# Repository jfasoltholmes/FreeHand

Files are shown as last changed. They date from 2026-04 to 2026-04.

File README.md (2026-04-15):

# FreeHand 🤖✋

<p align="center">
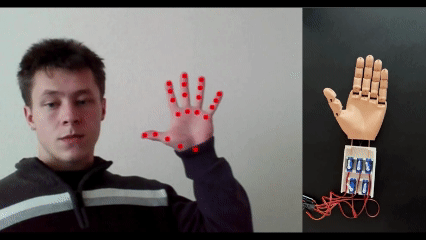
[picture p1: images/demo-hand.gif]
  
</p>

<p align="center">
  Real-time hand tracking → physical robotic hand using computer vision + embedded systems
</p>

<p align="center">
  
  
  
  
  
</p>

## ⚡ Quick Start (Vision Only)

Run the hand tracking system locally (no hardware required):

```bash
git clone https://github.com/jfasoltholmes/FreeHand
cd FreeHand
mise install
uv sync
uv run python main.py
```

⚠️ This runs the computer vision pipeline only (hand tracking + landmark visualization).

See [Hardware Setup](#hardware--assembly-notes) for full system integration.

## Why FreeHand?

FreeHand demonstrates real-time human-to-robot motion mapping using accessible tools.
The goal is to bridge computer vision and physical interaction in a simple and reproducible system.

## 🧠 FreeHand Overview
FreeHand is a real-time hand tracking system using OpenCV and MediaPipe that maps human hand motion to a motorized, 3D-printed robotic hand.

This system combines:
- 👁️ Computer vision (MediaPipe hand tracking)
- 🎯 Signal mapping (finger distance normalization)
- ⚙️ Embedded control (Bluno Beetle v1.1 microcontroller)
- 🦾 Mechanical design (3D-printed articulated hand)

## 🏗️ System Architecture

### Software
 - Real-time hand tracking using MediaPipe
 - Landmark-based finger state extraction
 - Normalized distance mapping to control signals
### Hardware
 - Bluno Beetle v1.1 microcontroller
 - 5x SG90 Servo motors (one per finger)
 - External power distribution via screw terminal
 - 6V DC power supply (recommended high current, e.g. 10A)
### Mechanical
 - 3D-printed hand structure
 - 3D-printed servo wrist mounting bracket
 - Tendon-driver finger actuation using fishing line
 - Flexible joints and segmented finger design

## 📊 Project Status
### Implemented 
 - Real-time hand tracking via webcam
 - MediaPipe landmark detection
 - Finger state extraction using normalized distance
 - Per-finger calibration mapping (open/closed → servo angle)
 - Serial communication (Python → Bluno Beetle)
 - Real-time servo actuation (full hand control)
 - Thumb-specific control model (middle MCP reference)
 - Servo-safe motion range calibration

### Current Capabilities
 - Full real-time mapping from human hand → robotic hand
 - Per-finger independent control
 - Stable demo-ready motion with calibration tuning

## 🛠 Setup (Software + Hardware)
### Software Prerequisites
- Install [mise-en-place](https://mise.jdx.dev/) (manages project Python version)
- Install [uv](https://github.com/astral-sh/uv) (fast venv + dependency sync)
- A working webcam

### Software Setup
#### Clone the repo and enter it: 
```bash
git clone https://github.com/jfasoltholmes/FreeHand
cd FreeHand
```
#### Install/use the project’s Python version:
```bash
mise install
mise use -g python@$(cat .python-version)  # optional if you want it global
```
*(If you already have mise configured, mise install is usually enough.)*

#### Create the virtual environment + install deps from lockfile:
```bash
uv sync
```
#### Run:
```bash
uv run python main.py
```
#### Notes:
 - Ensure hand_landmarker.task remains in the project root (or update the path in main.py).
 - Press q to quit.

### Firmware Prerequisites
Required to modify or flash the microcontroller:

- Install [VSCode](https://code.visualstudio.com/)
- Install [PlatformIO Extension](https://platformio.org/)

### Hardware & Assembly Notes
#### Microcontroller Setup
- The Bluno Beetle v1.1 does not come with header pins pre-installed.
- Solder header pins to all required I/O and power pins before use.
- Firmware is built and flashed using PlatformIO in VSCode.
- The board connects to your computer via USB (must support data transfer, not power-only).
#### 3D Printed Components
- Hand model files and assembly instructions [here.](https://www.thingiverse.com/thing:242639)
- Servo mounting bracket [here.](https://www.thingiverse.com/thing:3940835/files)
#### Servo Preparation & Installation
1. Use 5x SG90 servo motors (one per finger).
2. Before installation, power each servo and rotate it to 0 degrees. 
3. Attach the servo lever arm with the point facing toward the hand.
4. Install servos into the wrist mount:
    - The mount includes screw holes, but super glue can be used for tighter placement.
    - Ensure spacing prevents servo arms from colliding.
#### Tendon Routing
- Use stiff fishing line as tendons.
1. Thread each line through the servo holder holes.
2. Continue routing through the base of the hand.
3. Feed through each finger segment.
4. Tie securely at the fingertips.
 - Once routed, lightly pretension each tendon and tie it to the servo arm.
#### Servo Mapping
- Each servo corresponds to a finger:

    | Servo Position | Finger |
    |----------------|--------|
    | Bottom Left    | Pinky  |
    | Top Left       | Ring   |
    | Top Middle     | Middle |
    | Top Right      | Index  |
    | Bottom Right   | Thumb  |

### Wiring

#### Signal Wiring (Bluno Beetle → Servos)
- Pinky → A0
- Ring → D2
- Middle → D3
- Index → D4
- Thumb → D5

#### Power Distribution
 - Each servo has a positive, ground, and signal. This is red, brown, and orange respectively.
 - **Power setup:**
    - Connect servo red wires → screw terminal A rail (positive) via stripped Dupont wire
    - Connect servo brown wires → screw terminal B rail (ground) via stripped Dupont wire
    - Use terminals A1–A5 / B1–B5 (pinky → thumb)
- **Common Ground:**
    - Connect Bluno Beetle GND → B6 on the screw terminal using a stripped Dupont wire.
- **External Power:**
    - Use a 6V DC power supply connected to the screw terminal.
    - Positive → A rail
    - Ground → B rail

## 🔄 System Behavior
- The system tracks hand motion via webcam in real-time
- Finger positions are mapped to normalized distances
- Distances are converted to calibrated servo angles per finger
- Angle values are streamed via serial to the Bluno Beetle
- The robotic hand mirrors the user's hand motion continuously

## 🖼 Visual References

### Screw Terminal Wiring
<p align="center">
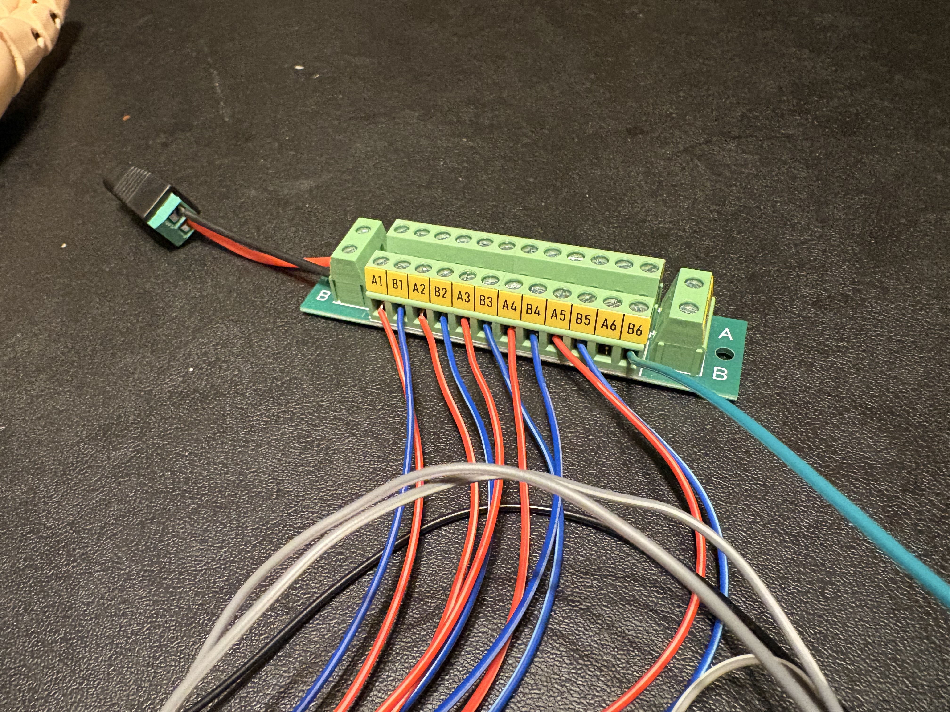
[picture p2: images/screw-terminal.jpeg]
  
</p>
<p align="center">
  <em>Servo positive (red) and ground (blue) wiring. Shared ground (green).</em>
</p>

### Bluno Beetle
<p align="center">
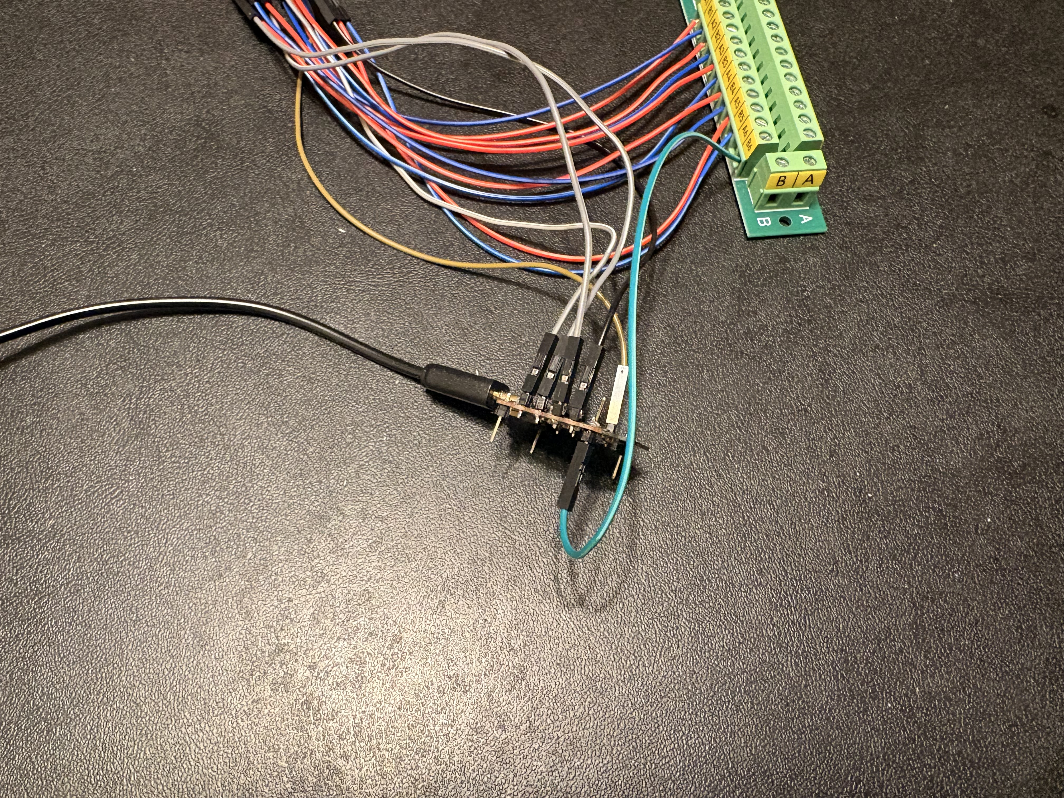
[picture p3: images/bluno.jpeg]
  
</p>
<p align="center">
  <em>Servo signal connected via Dupont wires. Shared ground (green).</em>
</p>

### Servo Wrist Bracket
<p align="center">
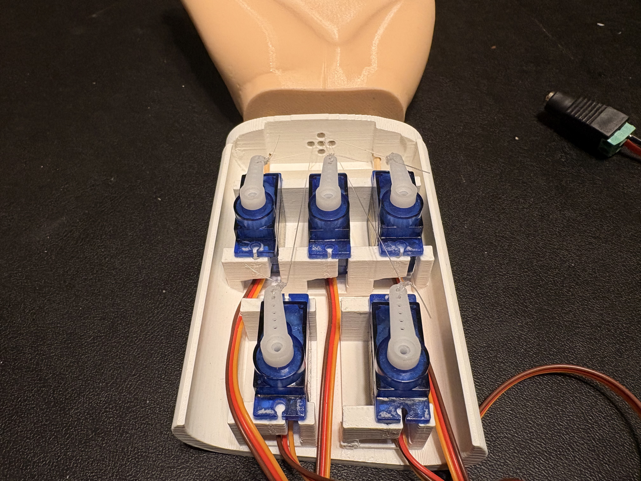
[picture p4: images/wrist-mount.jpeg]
  
</p>
<p align="center">
  <em>Fishing line routing from servos to fingertips.</em>
</p>

### Hand
<p align="center">
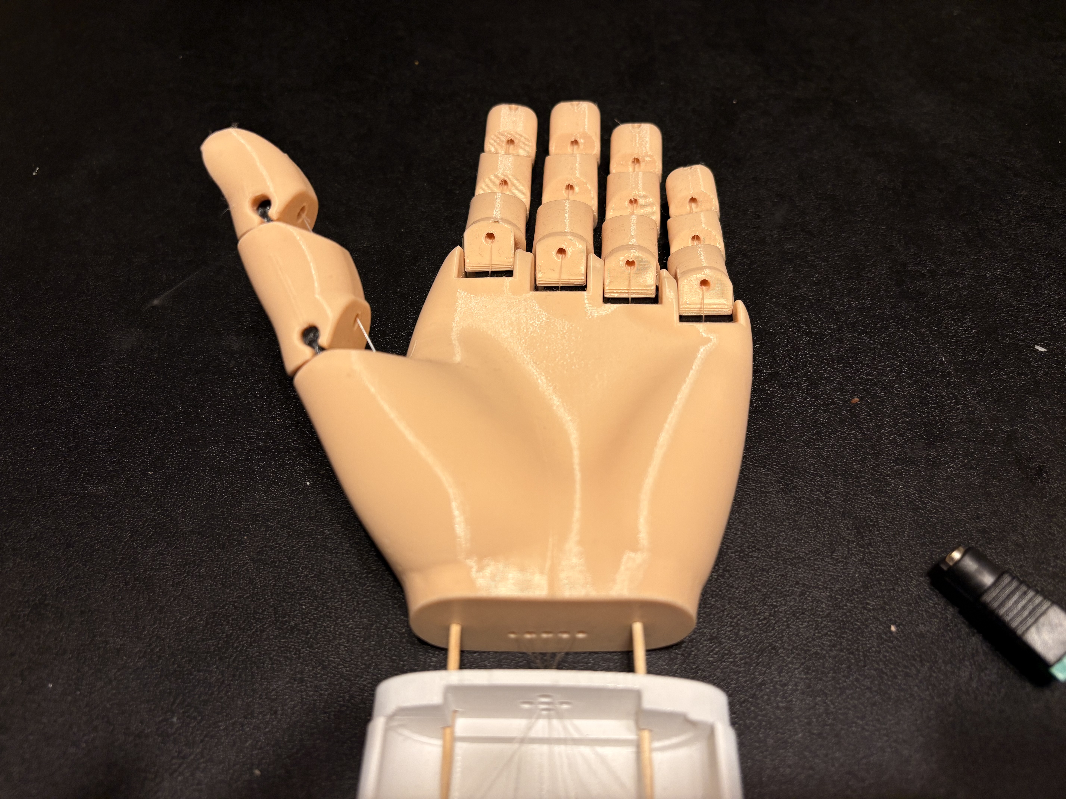
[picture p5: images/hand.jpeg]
  
</p>
<p align="center">
  <em>3D-printed hand in relaxed pose.</em>
</p>

## 📁 Repository Structure
```bash
FreeHand/
├── firmware/              # Embedded code (Bluno Beetle via PlatformIO)
├── handfiles/             # 3D printable hand components
├── images/                # README visuals and setup references
│
├── main.py                # Vision + serial control pipeline
├── hand_landmarker.task   # MediaPipe model
│
├── pyproject.toml         # Python dependencies
├── uv.lock                # Locked dependencies
├── mise.toml              # Python/toolchain management
├── .python-version
│
├── README.md
└── .venv/                 # Local environment (ignored)
```

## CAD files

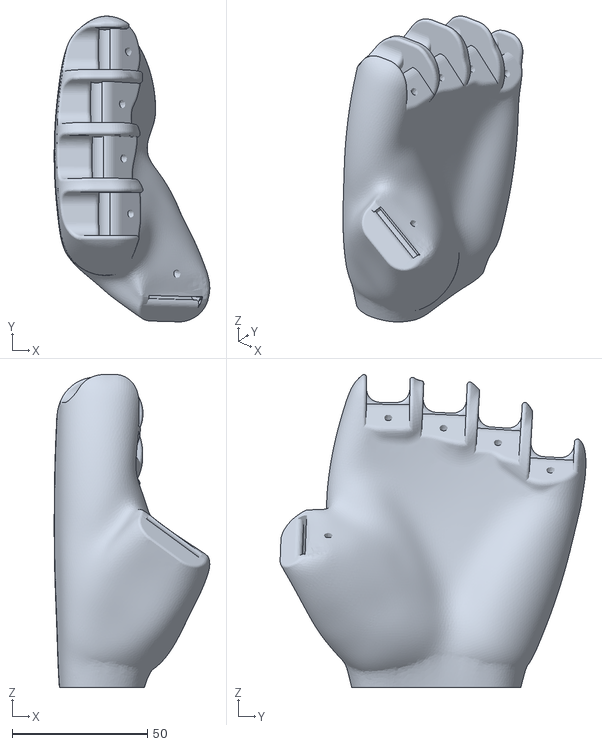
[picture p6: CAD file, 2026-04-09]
handfiles/6_-_90deg_Thumb.stl
57.5 x 112.9 x 115.6

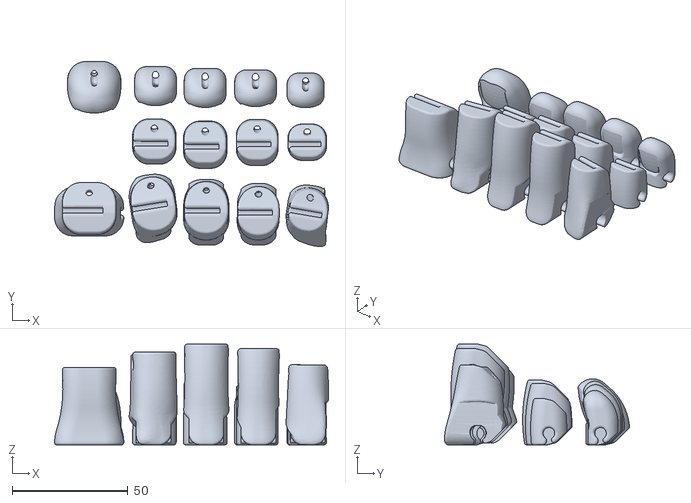
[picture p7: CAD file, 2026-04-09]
handfiles/LH_Finger_Plate.stl
118.3 x 79.9 x 43.5

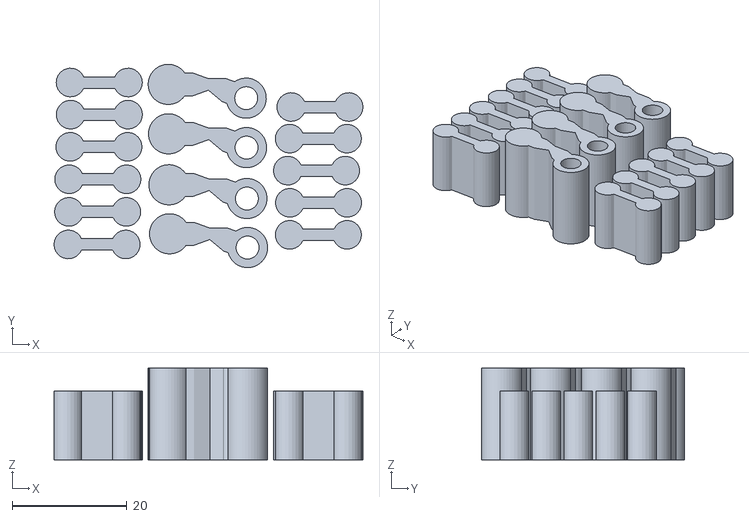
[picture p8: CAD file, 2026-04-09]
handfiles/FFX_-_Finger_Hinge_Plate.stl
53.8 x 35.4 x 16.0

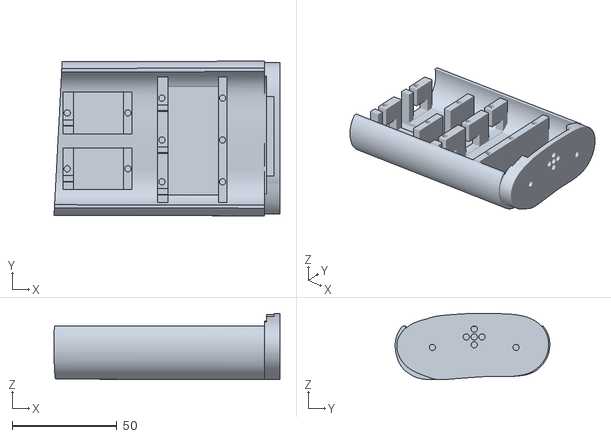
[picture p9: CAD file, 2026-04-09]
handfiles/hand_2.stl
108.0 x 73.9 x 31.6

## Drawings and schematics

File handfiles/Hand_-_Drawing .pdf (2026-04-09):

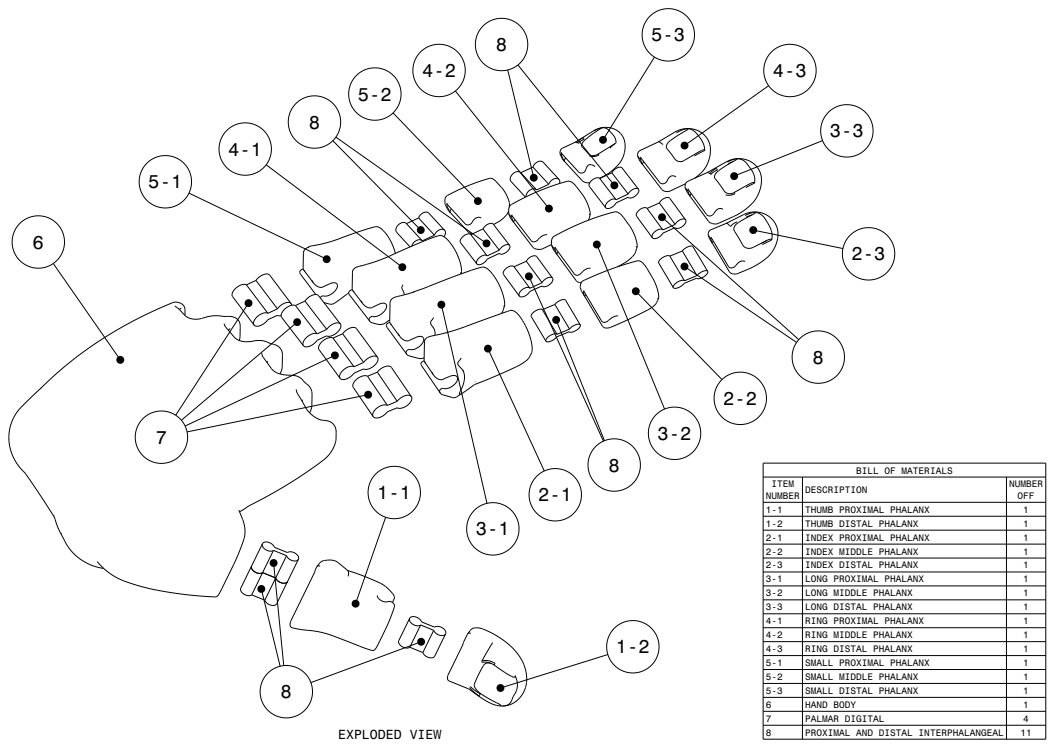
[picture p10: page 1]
EXPLODED VIEW; PROXIMAL AND DISTAL INTERPHALANGEAL

BILL OF MATERIALS

ITEM NUMBER | DESCRIPTION | NUMBER OFF

1-1 | THUMB PROXIMAL PHALANX | 1
1-2 | THUMB DISTAL PHALANX | 1
2-1 | INDEX PROXIMAL PHALANX | 1
2-2 | INDEX MIDDLE PHALANX | 1
2-3 | INDEX DISTAL PHALANX | 1
3-1 | LONG PROXIMAL PHALANX | 1
3-2 | LONG MIDDLE PHALANX | 1
3-3 | LONG DISTAL PHALANX | 1
4-1 | RING PROXIMAL PHALANX | 1
4-2 | RING MIDDLE PHALANX | 1
4-3 | RING DISTAL PHALANX | 1
5-1 | SMALL PROXIMAL PHALANX | 1
5-2 | SMALL MIDDLE PHALANX | 1
5-3 | SMALL DISTAL PHALANX | 1
6 | HAND BODY | 1
7 | PALMAR DIGITAL | 4

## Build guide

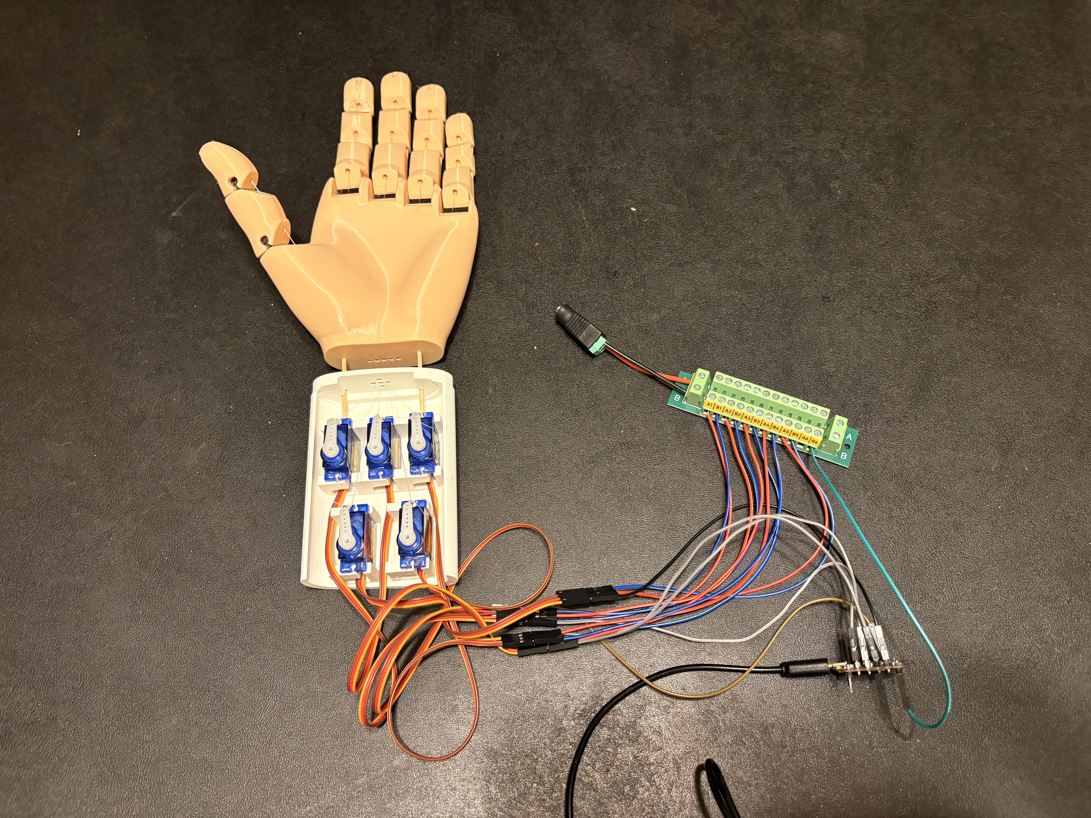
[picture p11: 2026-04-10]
images/setup-overview.jpeg

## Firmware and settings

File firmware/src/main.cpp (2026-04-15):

#include <Arduino.h>
#include <Servo.h>

bool parseAngles(const String& line, int output[5]);

// Create servo objects for each finger.
Servo thmb;
Servo pntr;
Servo midl;
Servo ring;
Servo pink;

// Min angles
const int THMB_MIN = 0;
const int PNTR_MIN = 0;
const int MIDL_MIN = 0;
const int RING_MIN = 0;
const int PINK_MIN = 0;

// Servo-safe max angles
const int THMB_MAX = 150;
const int PNTR_MAX = 170;
const int MIDL_MAX = 170;
const int RING_MAX = 170;
const int PINK_MAX = 170;

// Current angles
int thmb_pos = 0;
int pntr_pos = 0;
int midl_pos = 0;
int ring_pos = 0;
int pink_pos = 0;

String incomingLine = "";

void setup() {
  Serial.begin(9600);

  // Attach each servo obj to corresponding analog and digital pins.
  thmb.attach(5);
  pntr.attach(4);
  midl.attach(3);
  ring.attach(2);
  pink.attach(A0);

  // Initialize positions to 0 deg.
  thmb.write(thmb_pos);
  pntr.write(pntr_pos);
  midl.write(midl_pos);
  ring.write(ring_pos);
  pink.write(pink_pos);
}

void loop() {
  if (Serial.available() > 0) {
    incomingLine = Serial.readStringUntil('\n');
    incomingLine.trim();

    int parsed[5];
    if (parseAngles(incomingLine, parsed)) {
      // Parsed order: [thumb, pointer, middle, ring, pinky]
      thmb_pos = constrain(parsed[0], THMB_MIN, THMB_MAX);
      pntr_pos = constrain(parsed[1], PNTR_MIN, PNTR_MAX);
      midl_pos = constrain(parsed[2], MIDL_MIN, MIDL_MAX);
      ring_pos = constrain(parsed[3], RING_MIN, RING_MAX);
      pink_pos = constrain(parsed[4], PINK_MIN, PINK_MAX);

      thmb.write(thmb_pos);
      pntr.write(pntr_pos);
      midl.write(midl_pos);
      ring.write(ring_pos);
      pink.write(pink_pos);
    }
  }
}

// Angle parser: "thumb,pointer,middle,ring,pinky"
bool parseAngles(const String& line, int output[5]) {
  int first = line.indexOf(',');
  int second = line.indexOf(',', first + 1);
  int third = line.indexOf(',', second + 1);
  int fourth = line.indexOf(',', third + 1);

  if (first == -1 || second == -1 || third == -1 || fourth == -1) {
    return false;
  }

  // Thumb to pinky
  output[0] = line.substring(0, first).toInt();             // Thumb
  output[1] = line.substring(first + 1, second).toInt();    // Index
  output[2] = line.substring(second + 1, third).toInt();    // Middle
  output[3] = line.substring(third + 1, fourth).toInt();    // Ring
  output[4] = line.substring(fourth + 1).toInt();           // Pinky

  return true;
}

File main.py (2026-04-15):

import mediapipe as mp
from mediapipe.tasks import python
from mediapipe.tasks.python import vision

import cv2
import math
import serial
import time, logging
import numpy as np

# Establish serial connection
serial_conn = serial.Serial(port='COM4', baudrate=9600)
time.sleep(2) 

last_timestamp = 0

# Contains latest snapshot of detected hand landmarks.
callback_results = None

# Mapping with hard coded norm values
calibration = [
    {"open_norm": 0.97, "closed_norm": 0.38, "min_angle": 0, "max_angle": 150}, # Thumb
    {"open_norm": 1.85, "closed_norm": 1.15, "min_angle": 0, "max_angle": 170}, # Index
    {"open_norm": 1.93, "closed_norm": 1.14, "min_angle": 0, "max_angle": 170}, # Middle
    {"open_norm": 1.85, "closed_norm": 1.10, "min_angle": 0, "max_angle": 170}, # Ring
    {"open_norm": 1.82, "closed_norm": 0.62, "min_angle": 0, "max_angle": 170}  # Pinky
]

def map_to_angle(raw_value, finger_calibration):
    open_norm = finger_calibration["open_norm"]
    closed_norm = finger_calibration["closed_norm"]
    min_angle = finger_calibration["min_angle"]
    max_angle = finger_calibration["max_angle"]

    # Clamp raw value into expected range.
    raw_value = max(min(raw_value, open_norm), closed_norm)

    # Convert to 0-1 closed fraction (note inversion)
    closed_fraction = (open_norm - raw_value) / (open_norm - closed_norm)

    # Map to angle range
    angle = min_angle + closed_fraction * (max_angle - min_angle)

    return int(angle)

def callback(result, output_image, timestamp_ms):
    try:
        # Prototype assumes 1 hand in frame.
        global callback_results
        if not result.hand_landmarks:
            callback_results = None
            return
        hand = result.hand_landmarks[0]

        # Replace entire hand snapshot.
        callback_results = np.array([[lm.x, lm.y, lm.z] for lm in hand], dtype=np.float32)

    except Exception as e:
        logging.error(f"Error in callback function: {e}")

base_options = python.BaseOptions(model_asset_path='hand_landmarker.task')
running_mode = vision.RunningMode('LIVE_STREAM')
options = vision.HandLandmarkerOptions(base_options=base_options,
                                        running_mode=running_mode,
                                        num_hands=1,
                                        min_hand_detection_confidence=0.5,
                                        min_hand_presence_confidence=0.5,
                                        min_tracking_confidence=0.5,
                                        result_callback=callback)

with vision.HandLandmarker.create_from_options(options) as landmarker:
    webcam = cv2.VideoCapture(0)
    while True:
        _, frame = webcam.read()
        image_height, image_width, _ = frame.shape
        mp_image = mp.Image(image_format=mp.ImageFormat.SRGB, data=frame)

        # Ensure timestamps sent to detect_async are strictly increasing.
        timestamp = time.time()
        if timestamp <= last_timestamp:
            continue
        landmarker.detect_async(mp_image, mp.Timestamp.from_seconds(timestamp).value)
        last_timestamp = timestamp

        # Visualize landmarks and perform normalized distance calculations.
        if callback_results is not None:
            # imp_landmark structure:
            # idx 0:Wrist, 1:thumb tip, 2:index tip, 3:middle mcp, 4:middle tip, 5:ring tip, 6:pinky tip
            imp_landmarks = {0, 4, 8, 9, 12, 16, 20}
            coord_list = []
            norm_values = []
            angle_values = []

            # Display all 21 MediaPipe landmarks while storing important landmarks.
            for idx, fingertip_set in enumerate(callback_results):
                xloc, yloc = int(fingertip_set[0] * image_width), int(fingertip_set[1] * image_height)
                if idx in imp_landmarks:
                    # Store normalized float coordinates, while visualization uses integer pixel coordinates.
                    coord_list.append((fingertip_set[0], fingertip_set[1]))
                frame = cv2.circle(frame, (xloc, yloc), 5, (0, 0, 255), -1)
            
            # Normalize all finger distances by wrist to middle MCP distance (Relatively stable hand-size reference).
            hand_scale = math.dist(coord_list[0], coord_list[3])
            
            # idx refers to coord_list idx in this loop, not mediapipe landmark idx.
            for idx, coord_tuple in enumerate(coord_list):
                if idx == 0 or idx == 3:
                    continue
                
                if idx == 1:
                    # Thumb edge case: Calculate normalized distance from middle MCP to thumb tip.
                    norm_values.append(math.dist(coord_list[3], coord_tuple) / hand_scale)
                else:
                    # Calculate normalized distance from wrist to each finger tip.
                    norm_values.append(math.dist(coord_list[0], coord_tuple) / hand_scale)
                
            # Map to angle values
            for i in range(5):
                angle = map_to_angle(norm_values[i], calibration[i])
                angle_values.append(angle)

            serial_conn.write((','.join(map(str, angle_values)) + '\n').encode())

        # Flip frame horizontally for a mirrored webcam view.
        cv2.imshow('Hand Tracking', cv2.flip(frame, 1))
        if cv2.waitKey(1) == ord('q'):
            print("Closing Serial Connection")
            serial_conn.close()
            break

    webcam.release()
    cv2.destroyAllWindows()

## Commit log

2026-04-09 Initial firmware: basic servo control and finger test sequence
    [6_-_90deg_Thumb.stl, FFX_-_Finger_Hinge_Plate.stl, LH_Finger_Plate.stl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]
2026-04-12 Added calibrated mapping from normalized hand tracking to servo angles.
2026-04-12 Enabled real-time servo actuation by parsing and applying serial angle data on microcontroller.
2026-04-15 Refined per-finger calibration and add demo showcasing real-time hand control.
